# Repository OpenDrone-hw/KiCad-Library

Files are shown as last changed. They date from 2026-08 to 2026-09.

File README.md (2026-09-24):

# KiCad-Library

The parts catalogue of the OpenDrone hardware line: every physical symbol
links to an exact, committed datasheet, and every symbol, footprint and 3D
model here is used on a board that has been through a real assembly run. Its
job is lookup, not enforcement. Board repos pin this repository and keep only
parts that have not yet qualified in their local libraries.

## Repository layout

| Path | Contents |
|---|---|
| `symbol/OpenDrone.kicad_sym` | 54 symbols, one library, nickname `OpenDrone` |
| `footprint/OpenDrone.pretty/` | 145 footprints |
| `3dmodel/` | 246 model files (130 STEP, 116 WRL). Footprints reference the WRL set; the STEP set is the MCAD counterpart |
| `datasheet/` | Exact component PDFs, deduplicated by document and tracked by `manifest.json` |
| `PARTS-USED.md` | Every LCSC part used on a manufactured board, and which boards use it |
| `ALTERNATES.md` | Second sources for the FETs and gate drivers, grouped by land pattern and pinout |
| `tools/build-parts-index.py` | Regenerates `PARTS-USED.md`; `--check` audits membership |
| `tools/check-datasheets.py` | Verifies symbol coverage, paths, PDF signatures and SHA-256 hashes |
| `tools/build-pcm.py` | Builds the KiCad PCM package and repository metadata |
| `pcm/` | The PCM repository files KiCad reads |

## Usage

**As a KiCad package (easiest).** Preferences > Plugin and Content Manager >
Manage repositories, add:

```text
https://raw.githubusercontent.com/OpenDrone-hw/KiCad-Library/main/pcm/repository.json
```

Install "OpenDrone KiCad Library" from the Libraries tab. KiCad places the
content in its third-party directory and registers the libraries with a
`PCM_` prefix.

**In a board repo.** Every repo started from
[hardware-template](https://github.com/OpenDrone-hw/hardware-template) carries
this library as the git submodule `hardware/KiCad-Library`, pinned to a commit,
with the project's `OPENDRONE_LIB` text variable pointing at it. Parts place
straight from the `OpenDrone` library; `git submodule update --remote` pulls a
newer catalogue in. How to set that up and update it is in the org
[CONTRIBUTING](https://github.com/OpenDrone-hw/.github/blob/main/CONTRIBUTING.md).

**As a checkout.** Clone the repo, then in KiCad set a path variable
`OPENDRONE_LIB` (Preferences > Configure Paths) to the checkout directory.
Footprint 3D paths resolve through it. Add the libraries per project or
globally:

```text
(lib (name "OpenDrone")(type "KiCad")(uri "${OPENDRONE_LIB}/symbol/OpenDrone.kicad_sym")(options "")(descr "OpenDrone parts catalogue"))
(lib (name "OpenDrone")(type "KiCad")(uri "${OPENDRONE_LIB}/footprint/OpenDrone.pretty")(options "")(descr "OpenDrone parts catalogue"))
```

### Path contract (do not break)

Footprint 3D model paths are written as `${OPENDRONE_LIB}/3dmodel/<file>` and
symbol datasheet fields as `${OPENDRONE_LIB}/datasheet/<file>.pdf`. Board repos
define `OPENDRONE_LIB` as a project text variable, checkouts as a KiCad path
variable, and `tools/build-pcm.py` rewrites both prefixes to KiCad's third-party
directories when packaging. Keep new library items on those forms.

## Updating the library

1. Edit here, following the [rules](#rules).
2. Commit, push, PR to `main`.
3. After a merge that changes library content, rebuild and publish the
   package: `python3 tools/build-pcm.py <version>`, commit `pcm/`, then
   `gh release create pcm-v<version> dist/OpenDrone-KiCad-Library_<version>.zip`.

## Rules

**Membership.** Every reusable, datasheet-bearing component used on a board
whose repo is at `status-alpha` or beyond belongs here. Alpha means the board
was manufactured, so everything here has been through a real assembly run.
Parts that exist only on a planned or in-progress design do not qualify,
however good they look on paper. When a board reaches alpha, its ICs,
semiconductors, sensors, connectors and other non-generic parts join; ordinary
R/C/L/LED primitives remain in KiCad's standard libraries.

**Datasheets.** Every custom symbol for an orderable physical component maps to
one exact PDF in `datasheet/manifest.json`; a family PDF may serve several
symbols and is stored once. Set its `Datasheet` field to
`${OPENDRONE_LIB}/datasheet/<file>.pdf`. Virtual/interface symbols require an
explicit manifest exemption. Generic R/C/L primitives stay in KiCad's standard
libraries and do not get custom symbols or datasheet entries here. Product
repositories do not duplicate these PDFs.

**Check before you trust it.** `python3 tools/build-parts-index.py --check`
reports every symbol whose part is on no manufactured board, every symbol with
no LCSC number, every intentionally unpromoted generic primitive, and every
datasheet-bearing manufactured part still missing from the library. Missing
non-generic parts fail the check. Run it after any change here and after any
board reaches alpha.

**Authoring.** Edit symbols and footprints in the KiCad editors, or scripted
via kicad-skip or the pcbnew API; never text-edit `.kicad_sym` or `.kicad_mod`
files. Footprint references inside symbols use the `OpenDrone:` nickname, the
LCSC part number property is named `LCSC`, and 3D model paths follow the
[path contract](#path-contract-do-not-break). Do not add a symbol for every
value of a passive: [PARTS-USED.md](PARTS-USED.md) already answers which
resistors and capacitors we use. Validate before opening a PR:

```sh
kicad-cli sym export svg symbol/OpenDrone.kicad_sym -o /tmp/symcheck
kicad-cli fp upgrade /tmp/fpcheck   # on a copy of footprint/OpenDrone.pretty
python3 tools/check-datasheets.py

# every OpenDrone: footprint ref in the symbol lib resolves to a committed .kicad_mod
comm -23 <(grep -o '"OpenDrone:[^"]*"' symbol/OpenDrone.kicad_sym | tr -d '"' | sed 's/OpenDrone://' | sort -u) \
         <(ls footprint/OpenDrone.pretty | sed 's/\.kicad_mod$//' | sort)
# prints nothing when clean. kicad-cli does not flag a dangling footprint ref, so run this too
```

## Contributing

See [CONTRIBUTING.md](CONTRIBUTING.md).

## License

Licensed under [CERN-OHL-S-2.0](https://ohwr.org/cern_ohl_s_v2.txt), the same license as the boards. See [LICENSE](LICENSE).
Third-party PDFs retain their publishers' copyrights and notices.

## Revisions

- **2026-09-01**: exact component PDFs moved into the shared catalogue, linked
  through `OPENDRONE_LIB`, hash-checked by a manifest and included in PCM builds.
  The alpha-board audit then promoted every remaining datasheet-bearing part:
  54 symbols now map 53 physical components to 46 deduplicated PDFs, with one
  virtual exemption. The membership check fails when a future manufactured
  non-generic part is missing; 71 ordinary R/C/L/LED primitives remain outside
  the catalogue by design.
- **2026-08-15**: library nickname and files renamed `Incutec` to `OpenDrone`
  (`symbol/OpenDrone.kicad_sym`, `footprint/OpenDrone.pretty`). PCM package
  1.1.0. Board repos now carry the library as a pinned submodule from the
  template.
- **2026-08-14**: pruned to the membership rule: 41 symbols, 143 footprints,
  244 models remain, all on manufactured boards or awaiting an LCSC number.
  3D paths recontracted from the removed submodule layout to
  `${OPENDRONE_LIB}`. First PCM package published. `tools/bump-all.sh`
  deleted with the submodule model.
- **2026-08-04**: library assembled by merging the per-project board libraries: 105 symbols, 195 footprints, full 3D model set. LCSC property unified to `LCSC`, verified FC redraws adopted (`ESP32-C3FH4`, `SX1281IMLTRT`). `tools/bump-all.sh` fixed to commit via pathspec.
- **2026-06-29**: initial `Incutec.kicad_sym` from the OpenRX lineage (21 symbols).

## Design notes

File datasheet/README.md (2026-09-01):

# Datasheets

This directory pins the exact component documents linked from the shared KiCad
symbols. A board repository gets the same files by pinning this repository as a
submodule; it must not keep duplicate component PDFs in its own tree.

`manifest.json` is the source of truth. It maps every physical shared symbol to
one committed PDF and records the source URL and SHA-256 digest. A document may
cover several symbols, so family datasheets are stored only once. Virtual
symbols are listed explicitly under `exempt_symbols`.

Every reusable, datasheet-bearing component from a `status-alpha`,
`status-beta` or `status-launched` board belongs in the shared catalogue and in
this manifest. Generic R/C/L/LED primitives use KiCad's standard libraries and
do not need entries here. `python3 tools/build-parts-index.py --check` enforces
that distinction against all manufactured boards.

Run `python3 tools/check-datasheets.py` after adding or replacing a document.
PDFs retain their publishers' copyrights and notices; the repository hardware
license does not replace the terms embedded in those documents.

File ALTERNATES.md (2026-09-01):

# Alternates

Second sources for OpenDrone parts, grouped by the only thing that makes a
swap possible: one land pattern, one pinout, one function. A part listed here
fits the copper. Whether it fits the *board* is the second half of each
section, and that half disqualifies most candidates.

Nothing here is fitted. The fitted part is named at the top of each class and
is the only one that has been through an assembly run. Promoting an alternate
is a board change: datasheet read, stencil check, bench run, in that order.

Verified means the pinout or the parameter was read out of the manufacturer
datasheet. Screened means it came from a distributor parametric field and
nobody has opened the datasheet. Do not order against a screened row.

**Judge a package by its measured body, not its name.** Every vendor names its
own eight-lead power package and the names do not map onto each other:
Toshiba SOP Advance, Vishay PowerPAK SO-8, Infineon SuperSO8, Nexperia LFPAK56
and a generic PDFN5x6 are all the same size class. Whether one lands on our
copper is arithmetic on the datasheet drawing, not a question about the name,
and the answer for the 5x6 class is in that section.

MOSFET stock and price are JLCPCB parts API, checked 2026-08-29, at the 1000
break unless the row says otherwise. Gate driver rows are LCSC at 2026-08-27.
They move.

## Power MOSFET, DFN 5x6

Used on OpenESC-30x30, Q1-Q24, 24 per board.
Land pattern `4in1ESC-30x30:PDFN-8L_L6.0-W5.0-P1.27`: two rows of four leads
0.58 x 1.08 mm at y +/-2.83, so pads spanning y 2.29 to 3.37, 1.27 mm pitch,
plus a 4.4 x 4.1 mm drain pad centred at y -0.69. Pins 1-3 source, 4 gate,
5-8 drain.

Fitted: **SP40N01GHNK**, C22385416.

**The fitted part has two datasheet revisions under one part number, and they
disagree about the two parameters that decide this whole section.**

| | Ver-1.0 | Ver-1.1 |
|---|---|---|
| EAS | 490 mJ | 1089 mJ |
| RthJC | 1.27 C/W | 0.96 C/W |
| PD | 98 W | 130 W |
| Qg typ | 119 nC | 126 nC |

Both documents are internally self-consistent, so this is a real silicon or
process change that Siliup shipped without touching the MPN. That is exactly
the case where a reorder silently returns the older die. **Confirm the
revision against the reel date code before treating 1089 mJ as the bar.** The
table below is ranked against Ver-1.1. If Ver-1.0 is what ships, every row
from TPHR8504PL down improves relative to it.

Verified 2026-08-29. Every row read from the manufacturer datasheet.

| Part | Vendor | LCSC | Package, body mm | VDSS | RDS(on) max @10V | Qg @10V | EAS | RthJC | Stock | $@1k |
|---|---|---|---|---|---|---|---|---|---|---|
| SP40N01GHNK (fitted) | Siliup | C22385416 | PDFN5x6 | 40 V | 1.5 mOhm | 126 nC typ | 1089 mJ | 0.96 | 1632 | 0.331 |
| NCEP40T15AGU | NCE Power | C5119012 | DFN5X6-8L 4.90 x 6.00 | 40 V | 1.5 mOhm | 62 nC | 1620 mJ | 0.93 | 4017 | 0.490 |
| PSMN1R4-40YLD | Nexperia | C458253 | LFPAK56 4.9 x 6.0 | 40 V | 1.4 mOhm | 143 max | 1641 mJ | 0.56 | 802 | 0.315 |
| TPHR8504PL | Toshiba | C22388172 | SOP Advance, see note | 40 V | 0.85 mOhm | 103 nC | 336 mJ | 0.88 | 37632 | 0.517 |
| HYG009N04LS1C2 | Huayi | C2890387 | PDFN5x6-8L 5.20 x 6.15 | 40 V | 0.96 mOhm | 89 nC | 780 mJ | 2.0 | 14231 | 0.425 |
| XRS225N04LF | XinRui | C50314145 | PDFN-8L 5x6 | 40 V | 1.0 mOhm | 118 nC | 627 mJ | 1.1 | 1896 | 0.316 |
| NCEP40T13GU | NCE Power | C191993 | DFN5X6-8L 4.90 x 6.00 | 40 V | 2.3 mOhm | 70 max | 600 mJ | 1.56 | 7226 | 0.339 |
| CJAC200SN04U | JSCJ Changjing | C19268993 | PDFNWB5x6-8L | 40 V | 0.90 mOhm | 124 nC | 760 mJ | 1.2 | 1381 | 0.707 |
| APG013N04G | ALLPOWER | C5443733 | PDFN5x6-8L 5.10 x 6.05 | 40 V | 1.3 mOhm | 30 nC | 473 mJ | 1.9 | 3630 | 0.344 |
| BSC010N04LS6 | Infineon | C7220836 | SuperSO8 5.15 x 6.15 | 40 V | 1.0 mOhm | 83 max | 376 mJ | 1.0 | 4705 | 0.535 |
| DON160N04T | Doingter | C50386321 | DFN5x6 clip 5.20 x 6.05 | 40 V | 1.6 mOhm | 66 nC | 200 mJ | 1.5 | 2804 | 0.297 |

**EAS in mJ is not comparable across vendors.** Test inductance in this table
spans 18 uH to 0.5 mH, a 28x range, and energy scales with L at fixed current.
Back-computing avalanche current from EAS = 0.5 L I^2 is the honest
comparison, and it reorders the table:

| Part | IAS |
|---|---|
| TPHR8504PL | 120 A stated |
| NCEP40T15AGU | 80.5 A |
| HYG009N04LS1C2 | 72.1 A |
| SP40N01GHNK (fitted) | 66.0 A |
| DON160N04T | 63.2 A |
| XRS225N04LF | 56.0 A |
| CJAC200SN04U | 55.1 A |
| NCEP40T13GU | 49.0 A |
| APG013N04G | 43.5 A |

PSMN1R4-40YLD is the only part in the class publishing an avalanche curve
rather than a single point: 1641 mJ at ID 25 A and 446 mJ at ID 74 A, IAS
190 A, 100% tested.

**The gate is avalanche, not RDS(on).** OpenESC-30x30 has no input clamp. The
avalanche-rated FET *is* the overvoltage backstop, by design
(`OpenDrone-Testing/Tests/ESC/ESC-17-overvoltage-rationale.md`). 8S charged is
33.6 V against a 40 V part, so avalanche capability is the margin.

**30 V parts do not belong on this board.** 8S charged is above their
breakdown. A 30 V part is a valid alternate only if the board is re-rated to
6S. The 40 V floor is what buys 8S in the first place.

**Gate charge is not the binding constraint, and an earlier revision of this
file said it was.** The fitted part is 126 nC typ, not the ~70 nC previously
recorded here. The real arithmetic: 24 FETs x 126 nC x 24 kHz = 72.6 mA, so
the board already spends 12.1% of the LMR54406's 0.6 A rail on gate charge and
works. The worst part in the table, PSMN1R4-40YLD at 143 nC max, is 82.4 mA or
13.7%. Nothing here loads the rail meaningfully harder than what is fitted.
Driver dissipation and edge rate still move with Qg; rail headroom does not.

### Land pattern: almost everything in this size class fits

The reference drain land is 4.4 x 4.1 mm, larger than the fitted part's own
exposed pad at 4.01 x 3.48, so it has margin to spare. Computed from each
datasheet's own overall length, lead length and exposed pad, against pads
spanning y 2.29 to 3.37:

| Part | Lead y-span | Exposed pad |
|---|---|---|
| SP40N01GHNK (fitted) | 2.39-3.02 | 4.01 x 3.48 |
| NCEP40T15AGU | 2.39-3.00 | 3.81 x 3.58 |
| TPHR8504PL 2-5W1A | 2.40-3.05 | 4.21 x 3.69 |
| TPHR8504PL 2-5Q1S | 2.20-3.00 | 4.25 x 3.50 |
| DON160N04T | 2.38-3.02 | 4.00 x 4.10 |
| HYG009N04LS1C2 | 2.48-3.08 | 4.10 x 3.77 |
| JMSH0401AGQ | 2.38-3.08 | 4.10 x 3.53 |
| AGM403A1 | 2.39-3.08 | 4.01 x 3.48 |

**Nexperia LFPAK56 is the one genuine footprint outlier.** It is a copper clip
package with four gullwing leads on one side plus a drain tab, not an 8-lead
DFN. PSMN1R4-40YLD needs a second footprint and its own copper pour.

Three parts overrun a 5.2 x 6.2 window at maximum material condition and their
courtyards must be drawn to MMC, not nominal: HYG009N04LS1C2 (5.4 x 6.35),
JMSH0401AGQ (5.4 x 6.25) and XRS225N04LF (5.4 x 6.15).

**TPHR8504PL: one MPN, two packages.** Toshiba ships it as either 2-5Q1S
(SOP Advance, 5.0 x 6.0 overall, gullwing) or 2-5W1A (SOP Advance(N),
5.15 x 6.10 overall, flat lead). Both land on our pattern, per the table above,
so the ambiguity is not a blocker here, but the part number does not determine
what arrives and a stencil check has to cover both. Its V(BR)DSS is also
specified at ID = 10 mA, looser than the 250 uA every Chinese vendor in the
table uses, and V(BR)DSX collapses to 25 V min at VGS = -20 V.

### What actually beats the fitted part

**NCEP40T15AGU.** Higher avalanche current at an identical L = 0.5 mH test
condition, the only like-for-like avalanche comparison available. Half the gate
charge, marginally better RthJC, same RDS(on) max, lands on the existing
copper. Costs $3.81 more per board. 4017 pieces is 167 boards, so it has to be
reserved before a batch, not after.

**PSMN1R4-40YLD** is the strongest technical answer to what this board actually
fails at: copper clip with solder die attach, Rth(j-mb) 0.56 against the fitted
0.96, and the most rigorously characterised avalanche behaviour in the class.
It is currently cheaper than the fitted part. It is held back by 802 pieces and
by being the one real footprint job.

Note the fitted part is down to 1632 pieces, 68 boards. That is the near-term
constraint regardless of what this section concludes.

Not checked for any part in this class: repetitive avalanche EAR/IAR ratings,
AEC-Q101 status, MSL and reflow profile, and body-diode reverse recovery under
this board's real di/dt. Datasheet Qrr is measured at 100 A/us, likely
optimistic here.

## Power MOSFET, DFN 3x3

Used on OpenESC-20x20, Q1-Q24, 24 per board.
Land pattern `Package_SON:Diodes_PowerDI3333-8` (KiCad global library, not the
project library). Four lead pads 0.7 x 0.42 mm at x -1.5 on 0.65 mm pitch
(three source, one gate), four matching pads at x +1.5 for the drain leads, and
a 1.71 x 1.71 mm drain tab at x +0.455. The four drain-lead pads carry no pad
number in that footprint, so KiCad gives them no net: they solder to the part
but are invisible to DRC.

Fitted: **DOY180N03T**, C49441966, 30 V.

Verified 2026-08-29. AON7140, APG035N04Q and SP40N03GNJ were verified in the
2026-08-27 pass from datasheets in `OpenESC-20x20/hardware/datasheets/` and
their stock and price columns were not re-pulled, so those three are older than
the rest of the table.

| Part | Vendor | LCSC | Package, body mm | VDSS | RDS(on) @10V | Qg @10V | EAS | RthJC | Stock | $ |
|---|---|---|---|---|---|---|---|---|---|---|
| DOY180N03T (fitted) | Doingter | C49441966 | TDFN3333-8PL 3.30 x 3.30 | 30 V | 1.0 typ / 1.2 max | 39.8 nC | 100 mJ | 0.33, see note | 1815 | 0.184 @5k |
| DOY170N04T | Doingter | C50386319 | TDFN3333-8PL 3.30 x 3.30 | 40 V | 1.7 typ / 2.2 max | 39.8 nC | 200 mJ | 0.70 | 2437 | 0.286 |
| JMSL0302AU | JieJie JJM | C2890409 | PDFN3x3-8L 3.28 x 3.33 | 30 V | 1.2 typ / 1.5 max | 39 nC | 101 mJ | 2.5 max | 4680 | 0.157 @500 |
| IQE013N04LM6 | Infineon | C3289346 | PG-TSON-8-4 3.30 x 3.30 | 40 V | 1.1 typ / 1.35 max | 55 max | 255 mJ | 1.4 max | 90 | 1.582 |
| BSZ018N04LS6 | Infineon | C534643 | PG-TSDSON-8 FL 3.30 x 3.30 | 40 V | 1.6 typ / 1.8 max | 31 nC | 189 mJ | 1.8 max | 93 | 1.073 |
| AON7418 | Alpha & Omega | C74384 | DFN3.3x3.3, see note | 30 V | 1.4 typ / 1.7 max | 65 max | 109 mJ | 1.5 max | 483 | 0.341 |
| NCEP4065QU | NCE Power | C502974 | DFN3.3x3.3-8L 3.35 x 3.30 | 40 V | 2.2 typ / 2.8 max | 34.8 nC | 500 mJ | 2.3 | 1910 | 0.346 |
| TPN2R304PL | Toshiba | C5802634 | TSON Advance, see note | 40 V | 1.8 typ / 2.3 max | 41 nC | 39 mJ | 1.43 | 2595 | 0.457 |
| PTQ10HN03B | HT JinYu | C49384054 | PDFN3333 3.15 x 3.05 | 30 V | 3.1 typ / 4.0 max | 55 nC | 163 mJ | 2.31 | 4670 | 0.069 |
| XRS80N04D | XinRui | C50314143 | PDFN3333-8L 3.15 x 3.30 | 40 V | 3.4 typ / 4.5 max | 32 nC | 125 mJ | 1.9 max | 3025 | 0.102 |
| AON7140 | Alpha & Omega | C2758662 | DFN3x3 | 40 V | 1.9 typ / 2.3 max | 42 typ / 60 max | 135 mJ | not read | 2131 | 0.491 |
| APG035N04Q | ALLPOWER | C5443653 | PDFN3x3 | 40 V | 2.8 typ / 3.5 max | 20.3 nC | 100 mJ | 2.42 | 1436 | 0.143 |
| SP40N03GNJ | Siliup | C22466709 | PDFN3x3 | 40 V | 2.9 typ | 26 nC | 169 mJ | 2.27 | 958 | 0.111 @5k |
| PSMN3R3-40MSH | Nexperia | none | LFPAK33 (SOT1210), see note | 40 V | 2.6 typ / 3.3 max | 42 max | 200 mJ | 1.48 max | not listed | n/a |

Body dimensions not read from a mechanical drawing, so the package column is
screened for these three: **AON7418**, whose datasheet contains no package
outline drawing at all (the 3.3 x 3.3 is a page-1 label); **TPN2R304PL**, taken
from Toshiba's package designation; and **PTQ10HN03B**, whose name refers to
the 3.30 x 3.30 lead span, not the 3.15 x 3.05 body. PTQ10HN03B also publishes
two different bottom-view pad options under one package name with no statement
of which one ships.

EAS test conditions differ here as they do in the 5x6 class. AON7140 is at
L 0.3 mH and IAS 30 A, softer than the 0.5 mH the Doingter and NCE parts use,
so the mJ figures are not directly comparable.

**DOY170N04T is the only zero-work change in this class.** Same vendor, same
TDFN3333-8PL drawing symbol for symbol as the fitted part, so it drops onto the
existing land pattern. It doubles EAS to 200 mJ and buys 8S headroom, at
2.2 mOhm max against 1.2, roughly +83% conduction loss per FET.

**JMSL0302AU is the natural qualified second source.** 1.5 mOhm max against the
fitted 1.2 at the same 39 nC, with 2.6x the stock at 60% of the price and an
honestly published thermal number. It stays 30 V, so it does nothing for cell
count.

Every 40 V row costs conduction loss. The trade is cell count, since 30 V VDSS
is what caps OpenESC-20x20 and OpenAIO at 6S. Take a 40 V part only if the
board is being re-rated, and re-run the thermal case, not just the arithmetic.

**The thermal ranking in this class is unanchored.** The fitted part's stated
0.33 C/W RthJC is back-computed from PD = 379 W at TC = 25 C in a 3.3 x 3.3 mm
package, which is not a physical figure. The same vendor's identical package
drawing states PD = 179 W and RthJC = 0.70 C/W for DOY170N04T, a factor of two
in the same package. Nobody has measured either, and the measured 20x20 failure
mode is FET joint reflow, so this is the number that matters most and the one
least worth trusting.

Following from that: nobody has computed at what phase current DOY170N04T's
2.2 mOhm reaches the same die temperature the fitted part reaches at 1.2 mOhm,
on the 20x20's real copper and airflow. That calculation decides whether the
40 V drop-in is adoptable, and it needs a measured board RthJA, not a datasheet
RthJC.

Not buildable today: IQE013N04LM6 at 90 pieces, BSZ018N04LS6 at 93 and AON7418
at 483. At 24 FETs per board, 90 pieces is under four boards. BSZ018N04LS6 is
the best part in the class on paper and is effectively out of stock.

**PSMN3R3-40MSH is the only different thermal construction available.** LFPAK33
is a copper clip package rated to 175 C junction with 1.48 C/W max to the
mounting base, which is the most direct structural answer to solder joint
reflow. It has no LCSC listing, is Mouser/DigiKey/Farnell only, and needs a
completely new footprint: four clip leads on one side plus a drain mounting
base, not an 8-lead DFN. PSMN1R6-40YLC and PSMN1R8-40YLC were screened and
dropped earlier for being LFPAK56, which is the 5 x 6 package; LFPAK33 is the
3.3 x 3.3 member of the same family and does belong in this class.

## Three-phase gate driver, QFN-24 4x4

Used on OpenESC-30x30 (U4, U6, U8, U10), OpenESC-20x20 (U3, U7, U9, U11) and
OpenAIO, four per board.
Land pattern `4in1ESC:QFN-24_L4.0-W4.0-P0.50-TL-EP2.8`: 24 pads 0.55 x 0.28 mm
on 0.5 mm pitch, pin 1 top left, plus a 1.4 x 1.4 mm centre pad.

Fitted: **NSG2065Q**, C41414478.

Reference pinout, which every part below matches exactly:

| Pin | 1 | 2 | 3 | 4 | 5 | 6 | 7 | 8 | 9 | 10 | 11 | 12 |
|---|---|---|---|---|---|---|---|---|---|---|---|---|
| | LIN1 | LIN2 | LIN3 | VCC | NC | COM | NC | NC | LO3 | LO2 | LO1 | VS3 |

| Pin | 13 | 14 | 15 | 16 | 17 | 18 | 19 | 20 | 21 | 22 | 23 | 24 |
|---|---|---|---|---|---|---|---|---|---|---|---|---|
| | HO3 | VB3 | VS2 | HO2 | VB2 | VS1 | HO1 | VB1 | NC | HIN1 | HIN2 | HIN3 |

**An integrated bootstrap diode is mandatory.** Neither ESC carries a single
diode: the 30x30 board has 24 Q, 93 C, 81 R, 13 U and no D at all, and the
20x20 is the same. A pin-compatible driver without the internal diode has no
path to charge the bootstrap capacitor and will not run the high side.
Non-inverting input logic is also mandatory, because AM32 drives these
non-inverted.

| Part | LCSC | Pinout | Integrated BSD | Stock | $@1k |
|---|---|---|---|---|---|
| NSG2065Q (fitted) | C41414478 | verified | yes | 4876 | 0.239 |
| 6288Q-MNS | C49424413 | verified | yes | 9295 | 0.178 @5k |
| HL6288Q | C50331902 | verified | yes | 6020 | 0.182 @500 |
| SD6288Q | see note | verified | yes | n/a | n/a |
| JSM6288Q | C52196409 | verified | not confirmed | 2513 | 0.278 |
| FD6288Q | C328453 | verified | yes | 66 | n/a |
| NSG20652Q | C41414479 | screened | screened | 1367 | 0.310 |
| G2063Q | C49449773 | screened | screened | 5486 | 0.239 |
| HXFD6288QFN24 | C54423134 | screened | screened | 2967 | 0.227 @500 |
| SL6288Q | C53085155 | screened | screened | 417 | 0.126 @5k |
| ZH639D0NU | C53184465 | screened | screened | 1628 | 0.278 |

6288Q-MNS, HL6288Q and JSM6288Q pinouts were read from the datasheets in
`OpenESC-20x20/hardware/datasheets/`. FD6288Q is the original that the family
clones and is nearly out of stock; the clones are the supply.

SD6288Q has a verified pinout and integrated BSD but no LCSC listing under that
number. What LCSC stocks is **SD6287Q**, C44606225, 7458 pieces. In this family
the 6287 suffix marks the variant without the bootstrap diode, exactly as
FD6287 does against FD6288. Confirm before ordering; the datasheet on disk is
for the 6288.

Same package, will not work:

| Part | LCSC | Why not |
|---|---|---|
| DRV8300NLQ | C50345924 | Pin-compatible, pins 5 and 21 become MODE and DT and both default correctly when floating, but the **N** variant has no bootstrap diode. DRV8300D is the one with diodes. DRV8300DI and NI invert the low-side logic. |
| EG2124A | C2856308 | Pin-compatible three-phase driver, but its own datasheet specifies an external bootstrap diode. |
| AMT49406, SBD63006, FT1215Q, FT8132Q, FT8215Q, MS8829 | various | BLDC controllers with integrated output stages or I2C, not gate drivers. Unrelated pinouts. |

The 1.4 x 1.4 mm centre pad is worth noting: the NSG2065Q exposed pad is 2.6 to
2.8 mm square, so the land is about a quarter of its area. That undersizing
applies equally to every part in this table, which makes vendor differences in
exposed pad size irrelevant to the choice.

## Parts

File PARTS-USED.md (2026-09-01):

# Parts used

Every component that has actually been manufactured on an OpenDrone board.

A part is listed here only if it is used on a board whose repo is at
`status-alpha` or beyond, which means it has been through a real assembly
run: sourced, footprinted, and it survived a reflow oven. Parts that exist
only on a planned or in-progress design are deliberately absent, however
good they look on paper. When a board reaches alpha, its parts join.

Regenerate: `python3 tools/build-parts-index.py`

112 parts across 8 manufactured boards: OpenESC-20x20, OpenESC-30x30, OpenFC-Lite, OpenFC-Lite-Mini, OpenRX-Gemini, OpenRX-Lite, OpenRX-Lite-UFL, OpenRX-Mono.

| LCSC | Value | MPN | Footprint | Boards |
|---|---|---|---|---|
| C106225 | 10k | RC0201FR-0710KL | R_0201_0603Metric | OpenAIO, OpenESC-20x20, OpenESC-30x30, OpenFC-Core, OpenFC-Lite, OpenFC-Lite-Mini, OpenRX-Gemini, OpenRX-Lite, OpenRX-Lite-UFL, OpenRX-Mono |
| C76939 | 100nF | GRM033R61E104KE14D | C_0201_0603Metric | OpenAIO, OpenFC-Core, OpenFC-Lite, OpenFC-Lite-Mini, OpenRX-Gemini, OpenRX-Lite, OpenRX-Lite-UFL, OpenRX-Mono |
| C270365 | 10k | 0201WMF1001TEE | R0201 | OpenAIO, OpenESC-20x20, OpenESC-30x30, OpenFC-Core, OpenFC-Lite, OpenFC-Lite-Mini |
| C15525 | 10uF | CL05A106MQ5NUNC | C_0402_1005Metric | OpenAIO, OpenRX-Gemini, OpenRX-Lite, OpenRX-Lite-UFL, OpenRX-Mono |
| C206435 | 2.5nH | LQP03TN2N5C02D | L_0201_0603Metric | OpenAIO, OpenRX-Gemini, OpenRX-Lite, OpenRX-Lite-UFL, OpenRX-Mono |
| C206441 | 24nH | LQP03TN24NH02D | L_0201_0603Metric | OpenAIO, OpenRX-Gemini, OpenRX-Lite, OpenRX-Lite-UFL, OpenRX-Mono |
| C2168164 | 10nF | GRM033R61A103KA01J | C_0201_0603Metric | OpenAIO, OpenRX-Gemini, OpenRX-Lite, OpenRX-Lite-UFL, OpenRX-Mono |
| C2651081 | 2450FM07D0034T | 2450FM07D0034T | FILTER-SMD_4P-L1.0-W0.5-L | OpenAIO, OpenRX-Gemini, OpenRX-Lite, OpenRX-Lite-UFL, OpenRX-Mono |
| C2762594 | 22uF | CL10A226MO7JZNC | C_0603_1608Metric | OpenAIO, OpenESC-20x20, OpenESC-30x30, OpenFC-Lite, OpenFC-Lite-Mini |
| C2861882 | TLV75533PDQNR | TLV75533PDQNR | X2SON-4_L1.0-W1.0-P0.65-TL-EP | OpenAIO, OpenRX-Gemini, OpenRX-Lite, OpenRX-Lite-UFL, OpenRX-Mono |
| C2875272 | CJ17-400001010B20 | CJ17-400001010B20 | CRYSTAL-SMD_4P-L1.6-W1.2-BL | OpenAIO, OpenRX-Gemini, OpenRX-Lite, OpenRX-Lite-UFL, OpenRX-Mono |
| C2976675 | TS2306A 240GF MSM 9_C2976675 | TS2306A 240gf MSM 9 | SW-SMD_4P-L3.0-W2.0-P0.85-LS3.5 | OpenAIO, OpenFC-Core, OpenFC-Lite, OpenFC-Lite-Mini, OpenRX-Gemini |
| C5349953 | XL-1010RGBC-WS2812B | XL-1010RGBC-2812B | LED-SMD_4P-L1.0-W1.0-TL_XL-1010RGBC-WS2812B | OpenAIO, OpenRX-Gemini, OpenRX-Lite, OpenRX-Lite-UFL, OpenRX-Mono |
| C76935 | 1uF | GRM033R61A105ME44D | C_0201_0603Metric | OpenAIO, OpenRX-Gemini, OpenRX-Lite, OpenRX-Lite-UFL, OpenRX-Mono |
| C76991 | 10uF | GRM155R60J106ME44D | C_0402_1005Metric | OpenAIO, OpenRX-Gemini, OpenRX-Lite, OpenRX-Lite-UFL, OpenRX-Mono |
| C85891 | 15pF | GRM0335C1H150JA01D | C_0201_0603Metric | OpenAIO, OpenRX-Gemini, OpenRX-Lite, OpenRX-Lite-UFL, OpenRX-Mono |
| C85895 | 1.2pF | GRM0335C1H1R2BA01D | C_0201_0603Metric | OpenAIO, OpenRX-Gemini, OpenRX-Lite, OpenRX-Lite-UFL, OpenRX-Mono |
| C85926 | 470nF | GRM033R60J474KE90D | C_0201_0603Metric | OpenAIO, OpenRX-Gemini, OpenRX-Lite, OpenRX-Lite-UFL, OpenRX-Mono |
| C86125 | 2.0nH | LQP03TN2N0B02D | L_0201_0603Metric | OpenAIO, OpenRX-Gemini, OpenRX-Lite, OpenRX-Lite-UFL, OpenRX-Mono |
| C89334 | 2450AT18A100E | 2450AT18A100E | ANT-SMD_L3.2-W1.6 | OpenAIO, OpenRX-Gemini, OpenRX-Lite, OpenRX-Lite-UFL, OpenRX-Mono |
| C160407 | SM08B-SRSS-TB | SM08B-SRSS-TB(LF)(SN) | JST_SM08B-SRSS-TB | OpenESC-20x20, OpenESC-30x30, OpenFC-Lite, OpenFC-Lite-Mini |
| C166281 | 2.4k | RTT012401FTH | R_0201_0603Metric | OpenAIO, OpenFC-Core, OpenFC-Lite, OpenFC-Lite-Mini |
| C2107920 | 6.49k | AF0201FR-076K49L | R_0201_0603Metric | OpenAIO, OpenFC-Core, OpenFC-Lite, OpenFC-Lite-Mini |
| C270344 | 5.1k | 0201WMF5101TEE | R_0201_0603Metric | OpenAIO, OpenFC-Core, OpenFC-Lite, OpenFC-Lite-Mini |
| C270364 | 100k | 0201WMF1003TEE | R_0201_0603Metric | OpenAIO, OpenFC-Core, OpenFC-Lite, OpenFC-Lite-Mini |
| C88374 | Conn_Coaxial_Small | U.FL-R-SMT-1(80) | U.FL_Hirose_U.FL-R-SMT-1_Vertical | OpenAIO, OpenRX-Gemini, OpenRX-Lite-UFL, OpenRX-Mono |
| C965793 | LED_1_Green | XL-1005UGC  | LED_0402_1005Metric | OpenAIO, OpenFC-Core, OpenFC-Lite, OpenFC-Lite-Mini |
| C105226 | 22uF | CL05A226MQ5QUNC | C_0402_1005Metric | OpenESC-20x20, OpenESC-30x30, OpenFC-Lite |
| C106224 | 100k | RC0201FR-07100KL | R_0201_0603Metric | OpenAIO, OpenRX-Gemini, OpenRX-Mono |
| C106226 | 10R | RC0201FR-0710RL | R_0201_0603Metric | OpenAIO, OpenESC-20x20, OpenESC-30x30 |
| C150853 | SKY13373-460LF |  | QFN-12_EP_2x2_Pitch0.5mm | OpenAIO, OpenRX-Gemini, OpenRX-Mono |
| C151629 | SDM02U30LP3-7B | SDM02U30LP3-7B | X3-DFN0603-2_L0.6-W0.3-RD | OpenFC-Core, OpenFC-Lite, OpenFC-Lite-Mini |
| C160405 | SM06B-SRSS-TB(LF)(SN) | SM06B-SRSS-TB(LF)(SN) | CONN-SMD_SM06B-SRSS-TB-LF-SN | OpenAIO, OpenFC-Lite, OpenFC-Lite-Mini |
| C161488 | 2.2nF | GRM033R71E222KA12D | C_0201_0603Metric | OpenAIO, OpenRX-Gemini, OpenRX-Mono |
| C181043 | 100nF | GRM033R6YA104KE14D | C_0201_0603Metric | OpenAIO, OpenESC-20x20, OpenESC-30x30 |
| C19213 | RFX2401C | RFX2401C | QFN-16_L3.0-W3.0-P0.50-BL-EP1.7 | OpenAIO, OpenRX-Gemini, OpenRX-Mono |
| C192855 | 47nH | LQW15AN47NJ00D | L_0402_1005Metric | OpenAIO, OpenRX-Gemini, OpenRX-Mono |
| C194437 | 10uH | MLZ1608N100LT000 | L_0603_1608Metric | OpenAIO, OpenRX-Gemini, OpenRX-Mono |
| C19842466 | 0900PC16J0042001E | 0900PC16J0042001E | FILTER-SMD_10P-L2.0-W1.6-BL | OpenAIO, OpenRX-Gemini, OpenRX-Mono |
| C2058245 | INA186A3IDCKR | INA186A3IDCKR | SOT-363_SC-70-6 | OpenAIO, OpenESC-20x20, OpenESC-30x30 |
| C2074788 | 220 | ERJ-1GNF2200C | R_0201_0603Metric | OpenAIO, OpenRX-Gemini, OpenRX-Mono |
| C2151551 | SX1281IMLTRT | SX1281IMLTRT | QFN-24_L4.0-W4.0-P0.50-TL-EP2.6 | OpenAIO, OpenRX-Lite, OpenRX-Lite-UFL |
| C22355736 | LED_1_Blue | XL-1005UBC | LED_0402_1005Metric | OpenFC-Core, OpenFC-Lite, OpenFC-Lite-Mini |
| C22381772 | OW7EL89CENUYO3YLC-32M | OW7EL89CENUYO3YLC-32M | OSC-SMD_4P-L2.0-W1.6-BL_TXC_7Z | OpenAIO, OpenRX-Gemini, OpenRX-Mono |
| C22434896 | OW7EL89CENUNFAYLC-52M | OW7EL89CENUNFAYLC-52M | OSC-SMD_4P-L2.0-W1.6-BL_TXC_7Z | OpenAIO, OpenRX-Lite, OpenRX-Lite-UFL |
| C226468 | 220R | AC0201FR-07220RL | R_0201_0603Metric | OpenAIO, OpenESC-20x20, OpenESC-30x30 |
| C23733 | 4.7uF | CL05A475MP5NRNC | C_0402_1005Metric | OpenFC-Core, OpenFC-Lite, OpenFC-Lite-Mini |
| C2673087 | SN74LVC1G3157DTBR | SN74LVC1G3157DTBR | X2SON-6_L1.0-W0.8-BL | OpenFC-Core, OpenFC-Lite, OpenFC-Lite-Mini |
| C270363 | 12k | 0201WMF1202TEE | R_0201_0603Metric | OpenFC-Core, OpenFC-Lite, OpenFC-Lite-Mini |
| C273280 | 3.9k | RC0201FR-073K9L | R_0201_0603Metric | OpenFC-Core, OpenFC-Lite, OpenFC-Lite-Mini |
| C274337 | 200 | RC0201FR-07200RL | R_0201_0603Metric | OpenAIO, OpenRX-Gemini, OpenRX-Mono |
| C274342 | 10k |  | R0201 | OpenAIO, OpenESC-20x20, OpenESC-30x30 |
| C274878 | 75R | RC0201FR-0775RL | R_0201_0603Metric | OpenFC-Core, OpenFC-Lite, OpenFC-Lite-Mini |
| C2765098 | AT32F421G8U7 | AT32F421G8U7 | QFN-28_L4.0-W4.0-P0.40-TL-EP2.4 | OpenAIO, OpenESC-20x20, OpenESC-30x30 |
| C2836813 | BMI270 | BMI270 | LGA-14_L3.0-W2.5-P0.50-BR | OpenFC-Core, OpenFC-Lite, OpenFC-Lite-Mini |
| C2849580 | AP1606 | AP1606 | DFN-3L_L1.0-W0.6-P0.65-BR | OpenFC-Core, OpenFC-Lite, OpenFC-Lite-Mini |
| C2876045 | TLV7031DPWR | TLV7031DPWR | X2SON-4_L0.8-W0.8-P0.48-TL-A | OpenFC-Core, OpenFC-Lite, OpenFC-Lite-Mini |
| C2876234 | LP5912-1.8DRVR | LP5912-1.8DRVR | WSON-6-1EP_2x2mm_P0.65mm_EP1x1.6mm_ThermalVias | OpenFC-Core, OpenFC-Lite, OpenFC-Lite-Mini |
| C307331 | 100nF | CL05B104KB54PNC | C_0402_WIDE | OpenAIO, OpenESC-20x20, OpenESC-30x30 |
| C384956 | 10pF | GRM0335C1H100FA01D | C_0201_0603Metric | OpenAIO, OpenRX-Gemini, OpenRX-Mono |
| C39846837 | XRTC303020D4R7MBCA | XRTC303020D4R7MBCA | IND-SMD_L3.0-W3.0_AFE303020S | OpenAIO, OpenFC-Lite, OpenFC-Lite-Mini |
| C41414478 | NSG2065Q | NSG2065Q | QFN-24_L4.0-W4.0-P0.50-TL-EP2.8 | OpenAIO, OpenESC-20x20, OpenESC-30x30 |
| C415703 | 22uF | GRM155R60J226ME11D | C_0402_1005Metric | OpenFC-Core, OpenFC-Lite, OpenFC-Lite-Mini |
| C423739 | 1.4k | 0201WMF1401TEE | R_0201_0603Metric | OpenFC-Core, OpenFC-Lite, OpenFC-Lite-Mini |
| C459538 | DMN1150UFB-7B |  | DFN-3L_L1.0-W0.6-P0.65-BR | OpenFC-Core, OpenFC-Lite, OpenFC-Lite-Mini |
| C473048 | 10k |  | R0201 | OpenAIO, OpenESC-20x20, OpenESC-30x30 |
| C473509 | 680R | 0201WMF6800TEE | R_0201_0603Metric | OpenFC-Core, OpenFC-Lite, OpenFC-Lite-Mini |
| C473542 | 15R | 0201WMF150JTEE | R_0201_0603Metric | OpenAIO, OpenESC-20x20, OpenESC-30x30 |
| C474437 | 7.5k | RC0201FR-077K5L | R_0201_0603Metric | OpenAIO, OpenFC-Lite, OpenFC-Lite-Mini |
| C5187472 | TYPE-C 16P QTWT | TYPE-C 16P QTWT | USB-TYPE-C-SMD_TYPE-C-16P-QTWT | OpenAIO, OpenFC-Lite, OpenFC-Lite-Mini |
| C524780 | LP5912-3.3DRVR | LP5912-3.3DRVR | WSON-6-1EP_2x2mm_P0.65mm_EP1x1.6mm | OpenFC-Core, OpenFC-Lite, OpenFC-Lite-Mini |
| C5267406 | LSM6DSV16XTR |  | LGA-14_L3.0-W2.5-P0.50-BR | OpenFC-Core, OpenFC-Lite, OpenFC-Lite-Mini |
| C526944 | 470p | CC0201JRX7R9BB471 | C_0201_0603Metric | OpenFC-Core, OpenFC-Lite, OpenFC-Lite-Mini |
| C52923 | 1uF | CL05A105KA5NQNC | C_0402_1005Metric | OpenFC-Core, OpenFC-Lite, OpenFC-Lite-Mini |
| C57784 | 510R | RC0201FR-07510RL | R_0201_0603Metric | OpenFC-Core, OpenFC-Lite, OpenFC-Lite-Mini |
| C64890 | DSK24 | DSK24 | SOD-123_L2.8-W1.8-LS3.7-RD | OpenAIO, OpenFC-Lite, OpenFC-Lite-Mini |
| C66942 | 1nF | 0201B102K500NT | C_0201_0603Metric | OpenAIO, OpenRX-Lite, OpenRX-Lite-UFL |
| C695806 | 0.2mR | ASR-S-3-0.2F | R_2512_6332Metric | OpenAIO, OpenESC-20x20, OpenESC-30x30 |
| C7463385 | COS8051SOT | COS8051SOT | SOT-23-5_L3.0-W1.7-P0.95-LS2.8-BR | OpenFC-Core, OpenFC-Lite, OpenFC-Lite-Mini |
| C7498014 | LR1121IMLTRT | LR1121IMLTRT | QFN-32-1EP_5x5mm_P0.5mm_EP3.7x3.7mm | OpenAIO, OpenRX-Gemini, OpenRX-Mono |
| C7500381 | 1uF | CC0402KRX7R6BB105 | C_0402_1005Metric | OpenAIO, OpenESC-20x20, OpenESC-30x30 |
| C76928 | 100n | GRM033R60J104KE19D | C_0201_0603Metric | OpenFC-Core, OpenFC-Lite, OpenFC-Lite-Mini |
| C76937 | 100nF 16v |  | C0201 | OpenAIO, OpenESC-20x20, OpenESC-30x30 |
| C778391 | 30R | NQ01WMJ0300TEE | R_0201_0603Metric | OpenFC-Core, OpenFC-Lite, OpenFC-Lite-Mini |
| C85908 | 47p | GRM0335C1H470JA01D | C_0201_0603Metric | OpenAIO, OpenRX-Gemini, OpenRX-Mono |
| C85934 | 1n | GRM033R71H102KA12D | C_0201_0603Metric | OpenAIO, OpenRX-Gemini, OpenRX-Mono |
| C907939 | 220pF | GRM0335C1E221JA01D | C_0201_0603Metric | OpenAIO, OpenRX-Gemini, OpenRX-Mono |
| C98192 | 4.7uF 50v | CL21A475KBQNNNE | C_0805_2012Metric | OpenAIO, OpenFC-Lite, OpenFC-Lite-Mini |
| C166378 | 115k | RTT011153FTH | R_0201_0603Metric | OpenESC-20x20, OpenESC-30x30 |
| C2848334 | TLV76733DRVR | TLV76733DRVR | WSON-6_L2.0-W2.0-P0.65-TL-EP | OpenESC-20x20, OpenESC-30x30 |
| C320695 | 13.7k | RC-01W1372FT | R_0201_0603Metric | OpenAIO, OpenFC-Lite-Mini |
| C37635340 | XTM25012000JT00351001 | XTM25012000JT00351001 | CRYSTAL-SMD_4P-L2.5-W2.0-BL-A | OpenFC-Lite, OpenFC-Lite-Mini |
| C380366 | 4.7uF | TCC1206X7R475K500HT | C_1206_3216Metric | OpenESC-20x20, OpenESC-30x30 |
| C42411119 | AOTA-B201610S3R3-101-T | AOTA-B201610S3R3-101-T | IND-SMD_L2.0-W1.6_AOTA-B201610S3R3-101-T | OpenFC-Lite, OpenFC-Lite-Mini |
| C46594347 | FTC160808S4R7MBCA | FTC160808S4R7MBCA | IND-SMD_L1.6-W0.8_FTC160865SR47MBCA | OpenESC-20x20, OpenESC-30x30 |
| C48391583 | XRIM160808SR47MBCD |  | IND-SMD_L1.6-W0.8_FTC160865SR47MBCA | OpenESC-20x20, OpenESC-30x30 |
| C49441966 | DOY180N03T | DOY180N03T | Diodes_PowerDI3333-8 | OpenAIO, OpenESC-20x20 |
| C498185 | TF-021B-H265 | TF-021B-H265 | TF-SMD_TF-021B-H265 | OpenFC-Core, OpenFC-Lite-Mini |
| C5219261 | LMR51430YFDDCR | LMR51430YFDDCR | SOT-23-6_L2.9-W1.6-P0.95-LS2.9-BL | OpenAIO, OpenFC-Lite-Mini |
| C5219316 | LMR54406DBVR | LMR54406DBVR | SOT-23-6_L2.9-W1.6-P0.95-LS2.8-BR | OpenESC-20x20, OpenESC-30x30 |
| C5383002 | LMR51420YDDCR |  | SOT-23-6_L2.9-W1.6-P0.95-LS2.9-BL | OpenAIO, OpenFC-Lite-Mini |
| C76923 | 20p | GRM0335C1H200JA01D | C_0201_0603Metric | OpenFC-Lite, OpenFC-Lite-Mini |
| C152351 | 47948-0001 | 479480001 | ANT-SMD_47948-0001 | OpenRX-Lite |
| C160403 | SM03B-SRSS-TB | SM03B-SRSS-TB(LF)(SN) | CONN-SMD_SM03B-SRSS-TB-LF-SN-P | OpenFC-Lite |
| C160404 | SM04B-SRSS-TB | SM04B-SRSS-TB(LF)(SN) | CONN-SMD_4P-P1.00_SM04B-SRSS-TB-LF-SN | OpenFC-Lite |
| C22385416 | SP40N01GHNK | SP40N01GHNK | PDFN-8L_L6.0-W5.0-P1.27 | OpenESC-30x30 |
| C320741 | 19.1k | RC-01W1912FT | R_0201_0603Metric | OpenFC-Lite |
| C332577 | 8.87k | RTT018871FTH | R_0201_0603Metric | OpenFC-Lite |
| C393941 | TF PUSH | TF PUSH | TF-SMD_TF-PUSH | OpenFC-Lite |
| C39843328 | RP2354B_C39843328 | RP2354B | QFN-80_L10.0-W10.0-P0.40-TL-EP3.4 | OpenFC-Lite |
| C41378174 | RP2354A | RP2354A | QFN-60_L7.0-W7.0-P0.40-TL-EP3.4 | OpenFC-Lite-Mini |
| C45262770 | LMR51635YDDCR | LMR51635YDDCR | SOT-23-6_L2.9-W1.6-P0.95-LS2.8-BL | OpenFC-Lite |

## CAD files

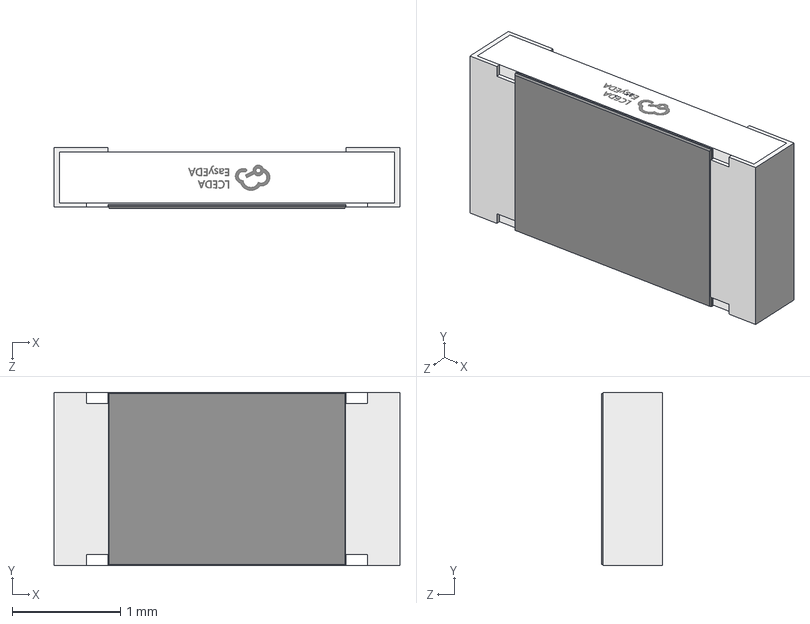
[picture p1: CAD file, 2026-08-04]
3dmodel/R1206_L3.2-W1.6-H0.6.step
3.20 x 1.60 x 0.56 mm

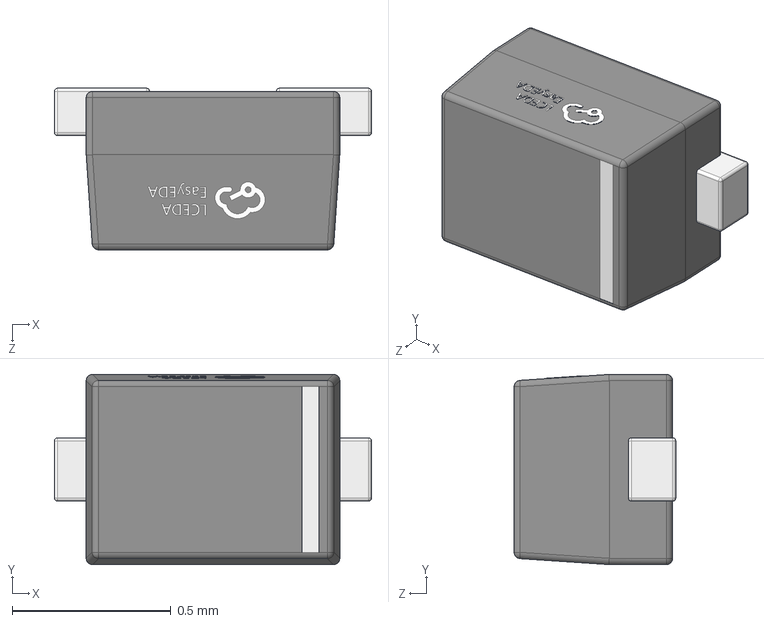
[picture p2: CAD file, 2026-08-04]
3dmodel/SOD-923_L0.8-W0.6-H0.5-LS1.0.step
1.00 x 0.6 x 0.51 mm

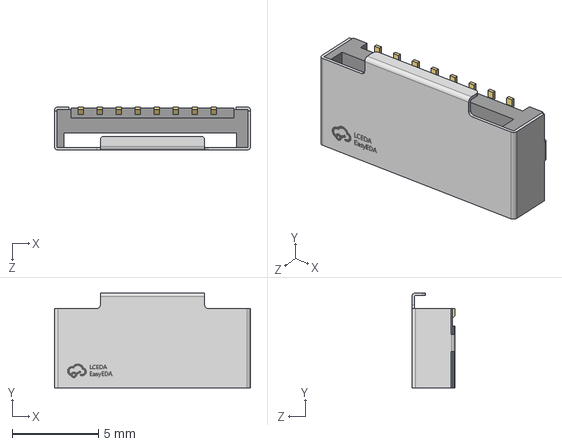
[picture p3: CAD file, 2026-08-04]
3dmodel/TF-SMD_TF-021B-H265.step
11.4 x 5.50 x 2.50 mm

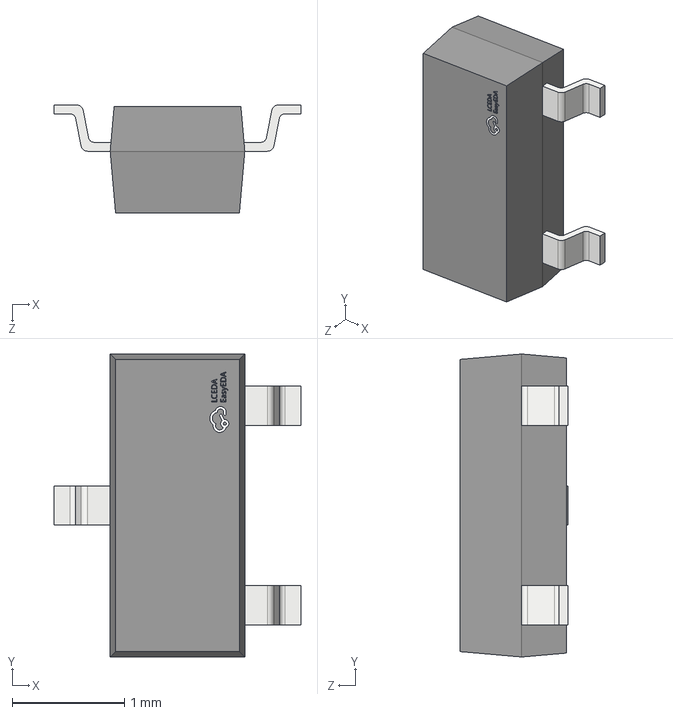
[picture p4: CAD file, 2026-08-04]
3dmodel/SOT-23-3_L2.9-W1.4-P1.91-LS2.6-BR.step
2.20 x 2.70 x 0.964 mm

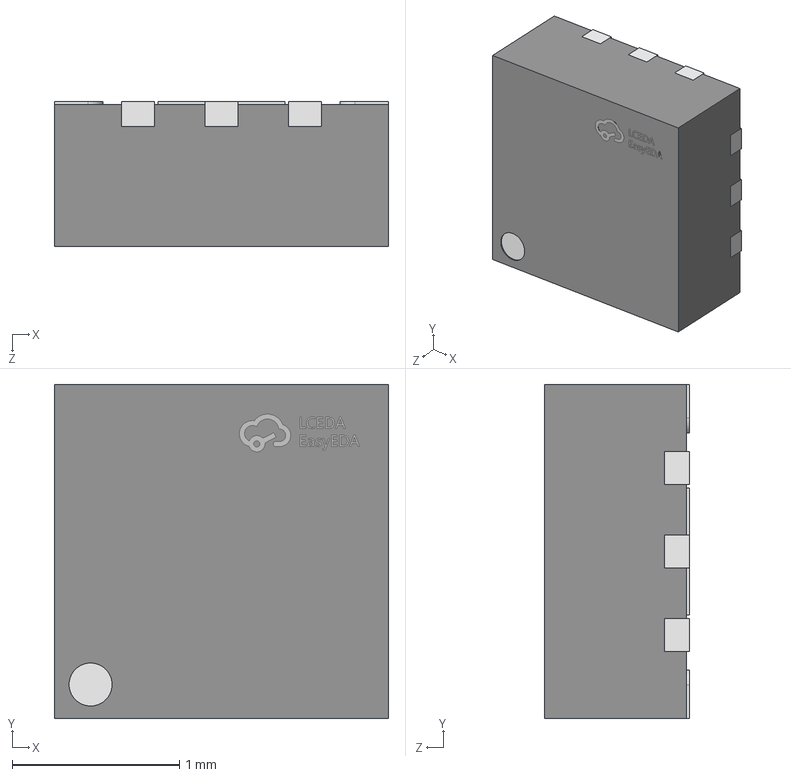
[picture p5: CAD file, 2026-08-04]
3dmodel/QFN-12_L2.0-W2.0-P0.50-BL-EP0.8.step
2.00 x 2.00 x 0.871 mm

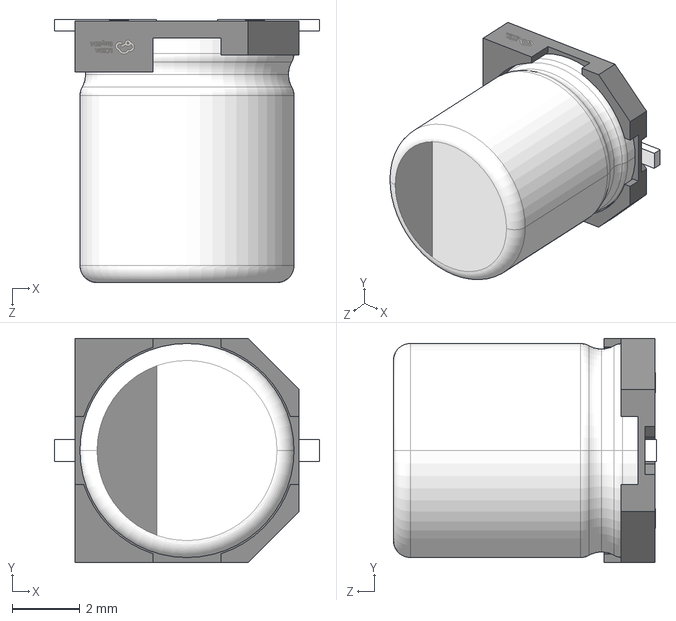
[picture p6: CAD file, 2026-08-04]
3dmodel/CAP-SMD_BD6.3-L6.6-W6.6-FD.step
7.80 x 6.60 x 7.75 mm

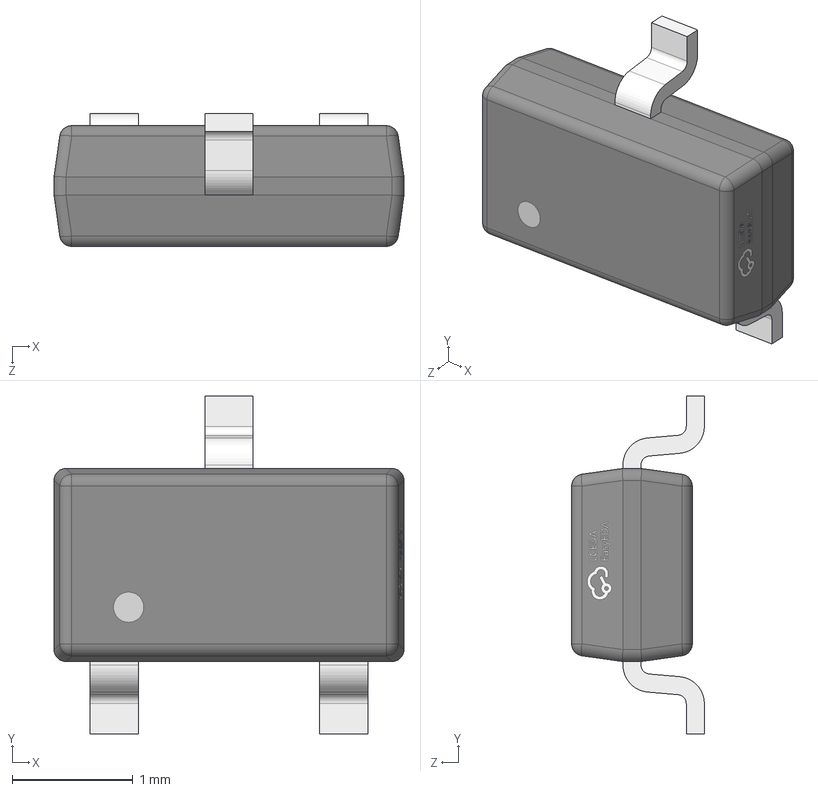
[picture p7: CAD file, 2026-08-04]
3dmodel/SOT-23-3L_L2.9-W1.6-H1.1-LS2.8-P0.95.step
2.90 x 2.80 x 1.10 mm

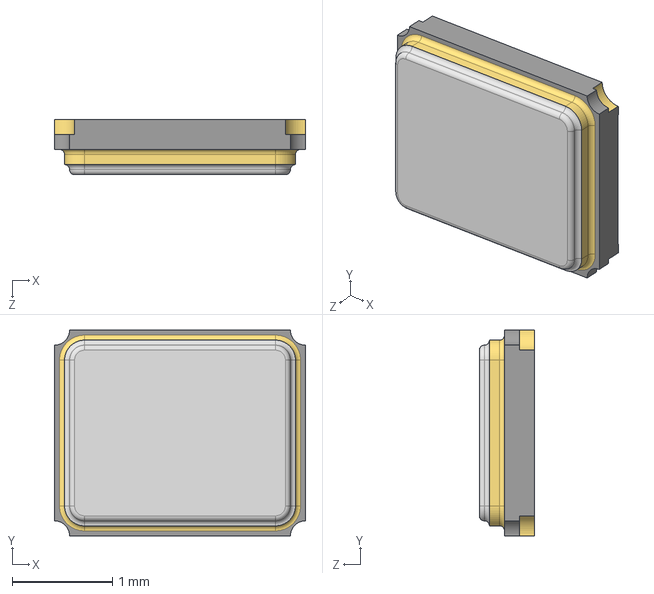
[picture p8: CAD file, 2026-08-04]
3dmodel/CRYSTAL-SMD_4P-L2.5-W2.0-BL-A.step
2.50 x 2.05 x 0.551 mm

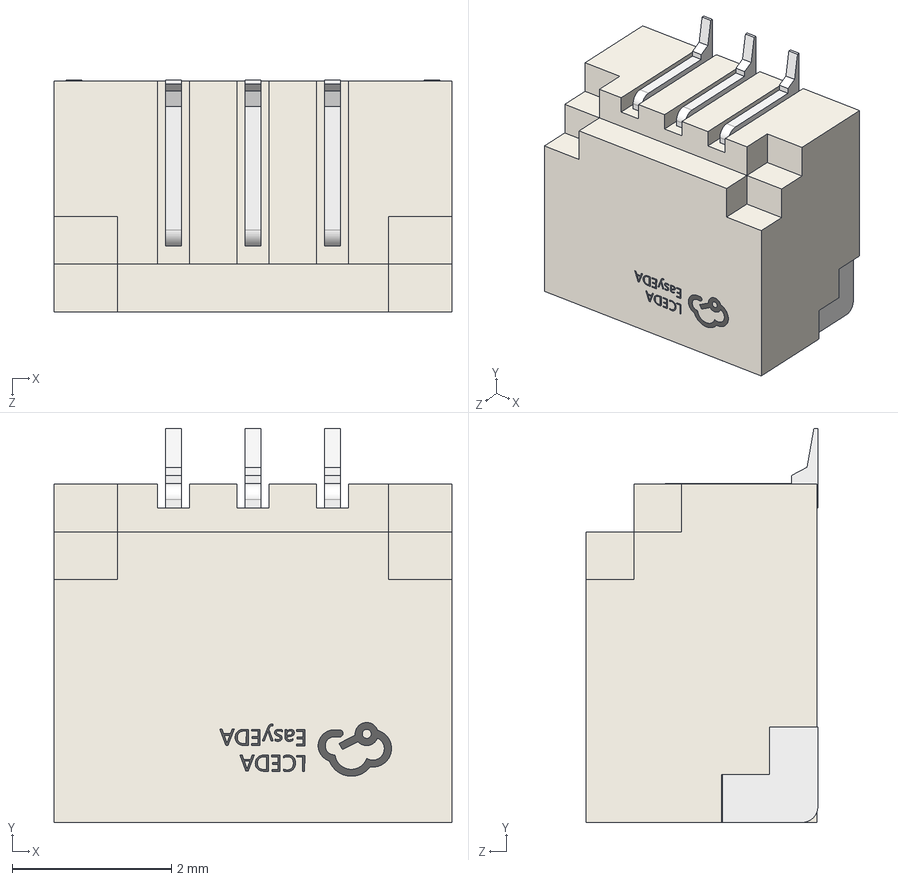
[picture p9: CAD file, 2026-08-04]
3dmodel/CONN-SMD_SR1.00-WS-3P.step
5.00 x 4.95 x 2.91 mm

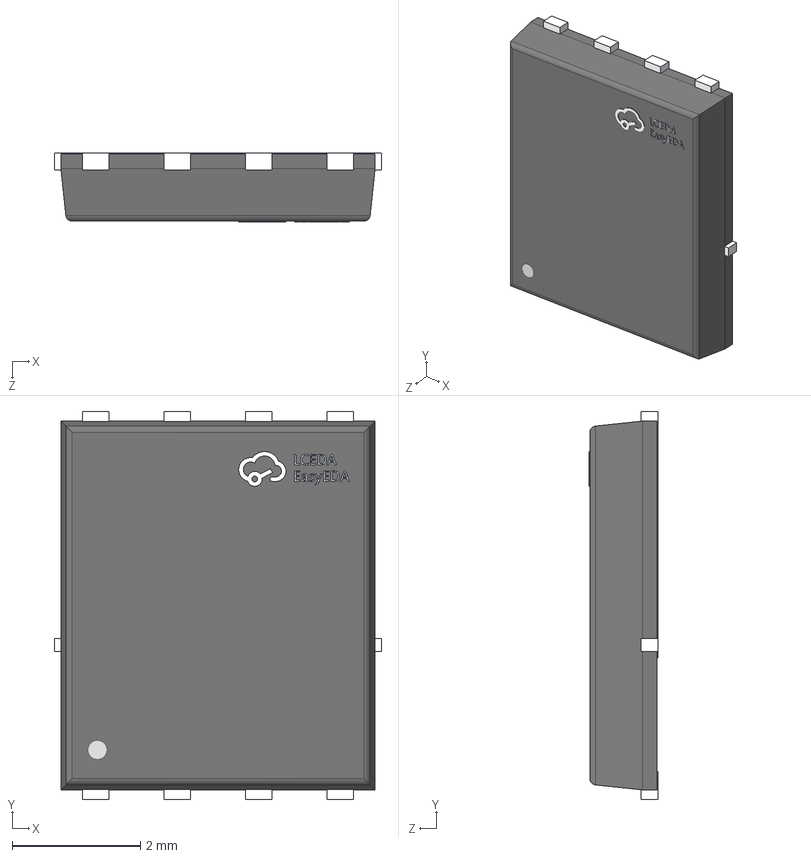
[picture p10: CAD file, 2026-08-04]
3dmodel/PDFN-8_L5.8-W4.9-P1.27-LS6.1-BL-A.step
5.10 x 6.05 x 1.07 mm

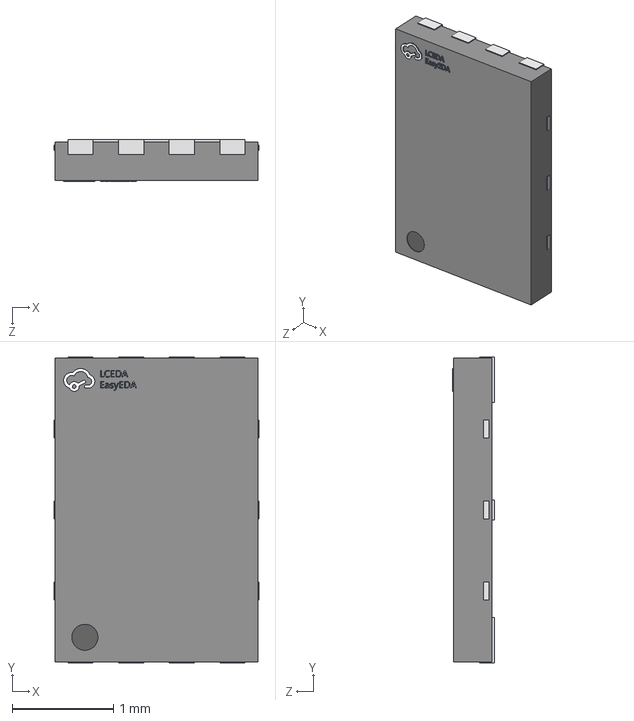
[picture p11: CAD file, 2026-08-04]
3dmodel/DFN-8_L3.0-W2.0-P0.50-BL-EP-3.step
2.02 x 3.02 x 0.41 mm

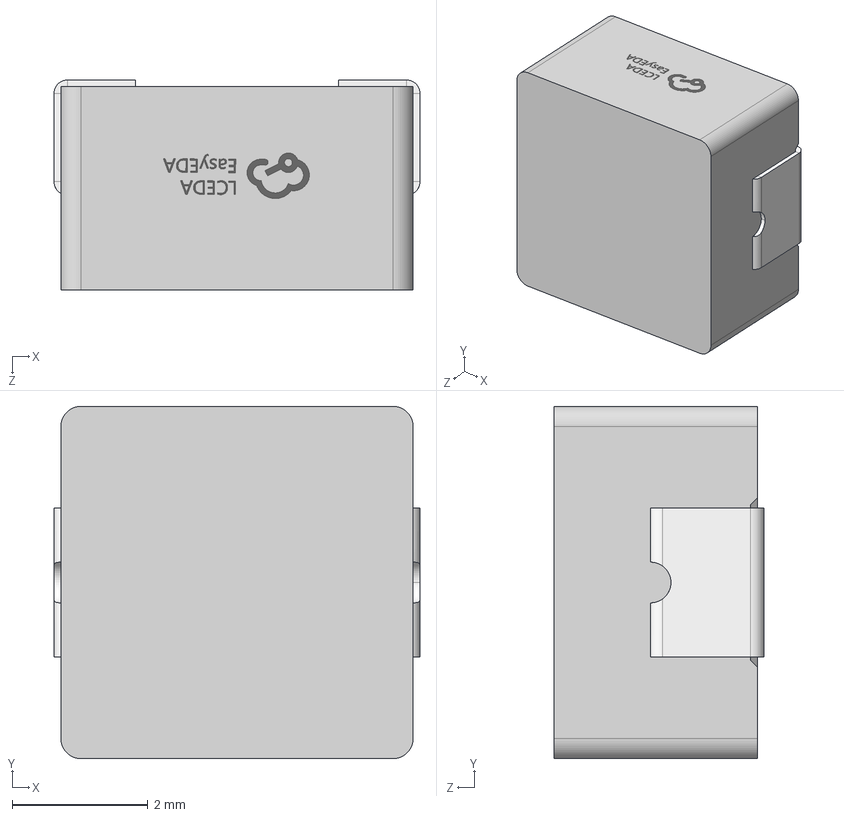
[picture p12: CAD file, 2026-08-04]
3dmodel/IND-SMD_L5.4-W5.2-H3.0.step
5.40 x 5.20 x 3.10 mm

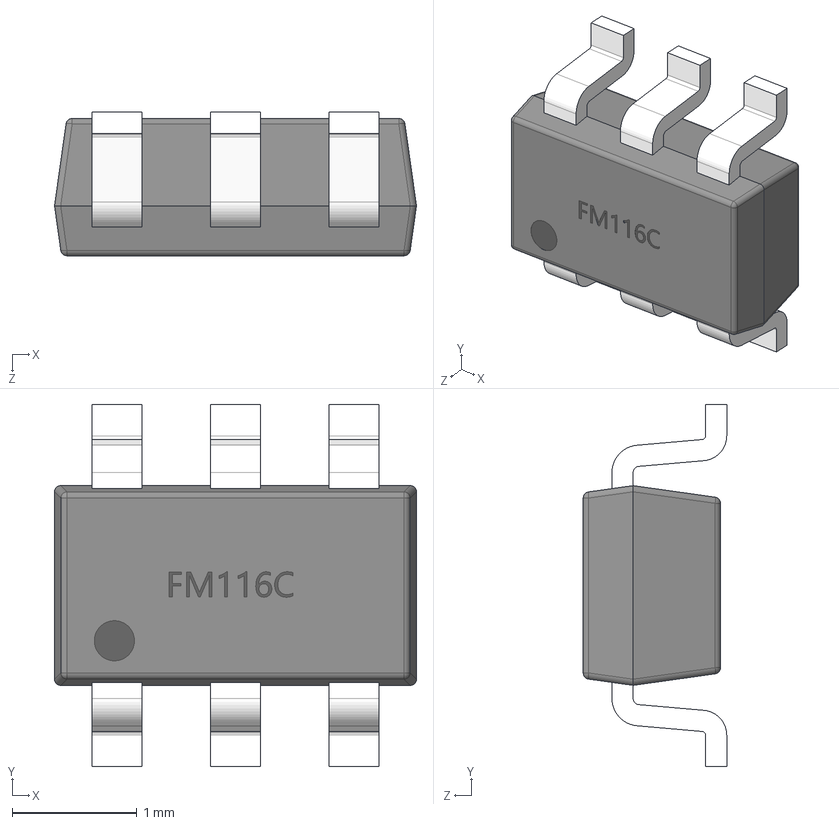
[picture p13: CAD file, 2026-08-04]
3dmodel/SOT-23-6_L2.9-W1.6-P0.95-LS2.9-BL.step
2.90 x 2.90 x 1.15 mm

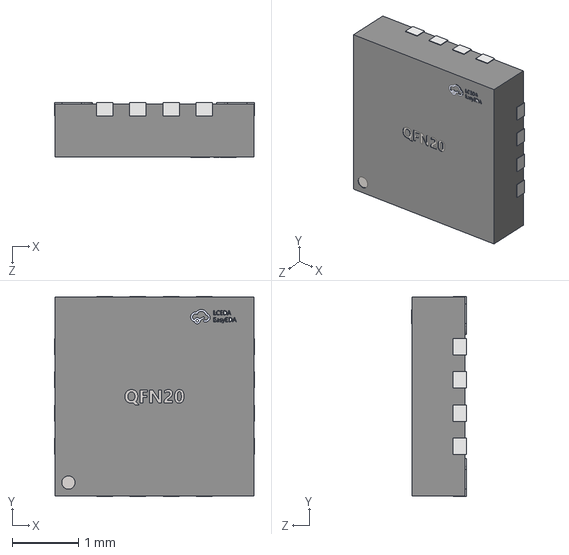
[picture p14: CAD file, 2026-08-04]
3dmodel/QFN-20_L3.0-W3.0-H0.8-P0.50.step
3.02 x 3.02 x 0.83 mm

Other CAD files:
3dmodel/U-DFN2020-6B_L2.0-W2.0-H0.6-P0.65.step
3dmodel/C0402_L1.0-W0.5-H0.5.step
3dmodel/OSC-SMD_4P-L3.2-W2.5-H1.0.step
3dmodel/LGA-14_L3.0-W2.5-P0.50-BR.step
3dmodel/ANT-SMD_L3.2-W1.6-H1.3.step
3dmodel/ANT-SMD_L3.2-W3.2-H4.0.step
3dmodel/C0805_L2.0-W1.3-H1.3.step
3dmodel/C1210_L3.2-W2.5-H2.5.step
3dmodel/CAP-SMD_BD6.3-L6.5-W6.5-LS7.2-FD.step
3dmodel/CONN-SMD_SR1.00-WS-4P.step
3dmodel/CONN-SMD_SR1.00-WS-5P.step
3dmodel/CONN-SMD_SR1.00-WS-6P.step
3dmodel/CONN-SMD_SR1.00-WS-8P.step
3dmodel/CONN-TH_5P-P3.96_JILN_JL396V-39605O01.step
3dmodel/CONN-TH_B9B-XH-A-LF-SN.step
3dmodel/CONN-TH_KF48RM-9.5-7P.step
3dmodel/CONN-TH_XH2.50-LI-7P.step
3dmodel/CONN-TH_XH2.50-LI-9P.step
3dmodel/CONN-TH_XT60PW-M.step
3dmodel/CRYSTAL-SMD_4P-L1.6-W1.2-BL.step
3dmodel/C_0201_0603Metric.step
3dmodel/C_0402_1005Metric.step
3dmodel/C_0603_1608Metric.step
3dmodel/C_0805_2012Metric.step
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

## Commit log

2026-08-04 feat: complete library, all product families merged
    Merge every per-project KiCad library into the canonical Incutec library:
    105 symbols, 195 footprints, full 3D model set. Footprint refs unified to
    the Incutec: nickname, model paths to the submodule path contract
    (${KIPRJMOD}/../libs/KiCad-Library/3dmodel/). Sources, collision decisions
    and validation in MANIFEST.md. Submodule-based usage documented in README.
    License CERN-OHL-S-2.0 to match the boards.
    [ANT-SMD_L3.2-W1.6-H1.3.step, ANT-SMD_L3.2-W3.2-H4.0.step, C0402_L1.0-W0.5-H0.5.step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]
2026-08-04 fix: unify LCSC property, adopt verified FC redraws
    Rename LCSC Part -> LCSC on 22 symbols (matches 929-use majority in
    existing schematics, bom skill export fields, Fabrication Toolkit).
    Adopt the newer FC drawings for ESP32-C3FH4 and SX1281IMLTRT after
    verifying pin-for-pin equality (numbers, names, electrical types).
2026-08-04 fix: bump-all commits via pathspec, never sweeps staged files
    A plain commit after add committed whatever else sat in a consuming
    repo's index. Pathspec commit takes only the submodule gitlink.
2026-08-05 docs: adopt OpenDrone repo standard
    Restructure README to the standard section order; add CONTRIBUTING.md,
    AGENTS.md, CHANGELOG.md; extend .gitignore; fix MANIFEST fact errors
    (RF footprint count, kicad-std 3D model wording, stale pre-rename and
    pre-archive source paths); update bump-all.sh run-dir comment to
    ~/OpenDrone/hardware.
2026-08-06 docs: fix contradictions and dedupe README/CONTRIBUTING
    - README 3dmodel row: the 336 models are not all footprint-referenced.
    188 of 195 footprints carry a model line, 160 WRL and 19 STEP distinct
    files; the rest of the STEP set is the MCAD counterpart.
    - Restore the frozen legacy-libs rule, truncated to "otes)." when
    MANIFEST.md was removed.
    - Authoring rules now live once, in CONTRIBUTING: editing method,
    Incutec: nickname, LCSC property name, pre-PR validation block.
    README Rules keeps only the board-repo facing rules.
    - CONTRIBUTING links to the README path contract and to
    "Updating the library" instead of restating them.
    - Add a dangling footprint-ref check to the pre-PR va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
2026-08-06 Adopt Bastian's library content: KiCad 10 footprints and corrected symbols
    His versions of 25 footprints replace legacy easyeda2kicad v5 dumps (module
    with tedit) with proper KiCad 10 footprints (version 20260206, real UUIDs),
    and his 21 symbols replace ours, carrying his verified footprint assignments.
    Kept from main so nothing breaks: all 105 symbols (his branch predates the
    consolidation and carries only 21), the directory layout the eight board
    repos point at, LICENSE, CONTRIBUTING and tools/.
    His footprints referenced 3D models through four schemes, including
    ${INCUTEC_LIB} which is undefined outside his machine and
    ${KIPRJMOD}/lib.3dshapes which would resolve into each consuming boar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
2026-08-06 Add used-parts index
    Answers the sourcing question directly: which parts, especially passives, are
    already used on a board, so they are sourced, footprinted and probably in
    stock. Generated from the board schematics, so nothing needs a library symbol
    to appear here. 214 parts across 8 boards.
    This is the alternative to adding a library symbol for every capacitor value.
2026-08-11 docs: ask contributors to raise proposals in Discord first
    CONTRIBUTING.md now points at the Discord server and asks contributors to tag
    the developers before opening an issue or starting work, so proposals get
    checked against work in progress, board locks and committed production runs.
2026-08-11 Add the generic QFN-16 3D model from bastian-changes
    QFN-16_L3.0-W3.0-H0.9-P0.50.step/.wrl are the only two files on
    bastian-changes that do not already exist in this library. OpenRX main
    references this model on the RFX2401C position, so without it those boards
    render with a missing model.
    The rest of that branch is the pre-reorganisation flat layout re-added on top
    of the current one: 26 footprints under Incutec.pretty/ and 38 3D models under
    Incutec.3dshapes/, all of which already exist under footprint/ and 3dmodel/.
    Verified before discarding: the symbol library is byte-identical between the
    two branches, and of the 26 footprints, 3 are byte-identical to ours and the
    other 23 have ident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
    [QFN-16_L3.0-W3.0-H0.9-P0.50.step]
2026-08-13 Make the membership rule checkable, and state it correctly (#14)
    The README contradicted itself: the opening paragraph said local project
    libraries are the working default and nothing needs to live here, the Rules
    section said new parts go here and only here. The first is the policy.
    Adds the real rule, and a way to check it. A part belongs here only if it is
    used on a board at status-alpha or beyond, so everything here has survived an
    assembly run. build-parts-index.py --check reads each repo's status-* topic and
    reports drift.
    First run says the library is close to inverted:
    105 symbols, of which 64 are for parts on no manufactured board
    21 symbols carry no LCSC number, so membersh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
2026-08-14 Prune to the membership rule, recontract 3D paths, publish as PCM package
    64 symbols on no manufactured board removed, with 53 footprints and 94
    model files nothing else references. 41 symbols remain: 20 mapped to
    manufactured LCSC parts, 21 awaiting an LCSC number (mostly OpenRX RF
    parts that are manufactured but unmapped). Validated: every remaining
    symbol renders, every footprint loads, no dangling footprint refs.
    3D paths move from the removed submodule layout to ${OPENDRONE_LIB},
    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
    [CONN-SMD_HC-1.0-8PWT.step, CRYSTAL-SMD_4P-L2.0-W1.6-BL.step, CRYSTAL-SMD_4P-L3.2-W2.5-BL.step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]
2026-08-15 Rename library nickname and files from Incutec to OpenDrone
    symbol/OpenDrone.kicad_sym, footprint/OpenDrone.pretty, footprint refs
    inside symbols now OpenDrone:. Tools and README follow. PCM package 1.1.0.
    README documents the submodule use from the template.
2026-08-15 Promote SOT-23-6_L2.9-W1.6-P0.95-LS2.8-BR footprint from OpenESC-20x20 (#18)
    Used by the LMR54406DBVR buck on the manufactured 4in1 ESC top sheet.
    [SOT-23-6_L2.9-W1.6-H1.5-LS2.8-P0.95.step]
2026-08-15 Revert PARTS-USED.md and status cache regenerated by --check in #18 (#19)
    OpenAIO has copied sheets but no manufactured board; the index gets
    regenerated deliberately, not as a side effect of a footprint promotion.
2026-08-22 3D models: retarget to KiCad stock, fix placement
    Replaces easyeda2kicad 3D models with KiCad's own where a dimension-matched
    equivalent exists. The easyeda models run 20-100x denser for the same package
    and most carry the LCEDA watermark modelled as raised geometry, which renders
    on every CAD picture of the board and is not on the real part.
    Only the (model ...) reference, offset and rotation are touched. No footprint,
    pad, land pattern, net, placement or value is modified. Applied to the footprint
    LIBRARY and the boards together: fixing only the .pretty is invisible because
    each board carries its own footprint copy, and fixing only the .kicad_pcb is
    surface level because the next placemen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
2026-09-01 Add ALTERNATES.md: second sources by land pattern and pinout
    Three compatibility classes covering the ESC power stage: DFN 5x6 FETs
    (30x30), DFN 3x3 FETs (20x20), and the QFN-24 4x4 FD6288Q-pinout gate
    driver shared by 30x30, 20x20 and OpenAIO.
    Pinouts and parameters are read from datasheets where the table says
    verified; LCSC parametric fields where it says screened. Two gates decide
    most of these: avalanche energy on the 30x30, because the board has no
    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
2026-09-01 Correct MOSFET alternates from the 2026-08-29 survey
    Two errors in the previous revision changed the conclusions:
    - SP40N01GHNK Qg is 126 nC typ, not the ~70 nC recorded. The board already
    spends 12.1% of the LMR54406 rail on gate charge and works, so gate charge
    is not the binding constraint and parts were rejected against a bar below
    what is fitted.
    - The fitted part ships under two datasheet revisions with the same MPN.
    Ver-1.0 is 490 mJ / 1.27 C/W, Ver-1.1 is 1089 mJ / 0.96 C/W. Confirm the
    revision against the reel date code before treating 1089 mJ as the bar.
    Land pattern: the reference drain land is larger than the fitted part's own
    exposed pad, so every DFN5x6 in the surv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
2026-09-01 Index split OpenRX board repositories
2026-09-24 docs: recount footprints and model files in README layout table (#22)
    README stated 143 footprints and 244 model files (129 STEP, 115 WRL). The
    catalogue has grown since the 2026-09-01 Revisions entry those numbers came
    from. Recounted directly from the tracked files: 145 .kicad_mod footprints,
    130 .step + 116 .wrl = 246 model files.
2026-10-12 docs(agents): cut AGENTS.md to validate, boundaries, pointers (#26)
    AGENTS.md 62 -> 15 lines. Removes architecture, tables, procedures and
    state; keeps only hard boundaries and the validation command.
    Claude-Session: https://claude.ai/code/session_017Ye54fa9v5VP179Xbw465R
2026-10-13 docs: restore AGENTS.md technical write-up (#27)
    Reverts the AGENTS.md cut and the README pointer change; the write-up is board documentation, not duplicated elsewhere.
    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
2026-11-11 docs(agents): drop the board Rules section (#32)
    The section is the shared rule set of board repositories. This library has no schematic, no ERC or DRC and no Environment section, so the rules pointed at commands that do not exist here.
